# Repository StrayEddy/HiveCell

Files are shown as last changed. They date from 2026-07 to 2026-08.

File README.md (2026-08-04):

# HiveCell



**🌐 Project site & demo video: [strayeddy.github.io/HiveCell](https://strayeddy.github.io/HiveCell/)**

> **Open-source hardware research — uncertified, not a deployable product.**
> HiveCell moves a powered steel piston through a space a person occupies. It is
> **design and simulation only**: no built hardware, no physical validation, no
> safety certification. **Do not build this to put a person inside it.** See
> [`LICENSE`](LICENSE) for the full safety notice and licensing.

Modular public sleeping infrastructure. Each cell is a recessed cavity in a large
wall that provides one clean, safe overnight sleeping space. When unavailable, the
cavity retracts into the wall until the public face is flush, moving the sleeping
surface into a hidden service area for automated cleaning.

Design priorities (in order): vandal resistance, hygiene, reliability, low
maintenance, low energy, low cost, simplicity, easy servicing, long lifetime.
Comfort is intentionally low priority.

## Mechanism

**True syringe (Option B):** a single piston moves inside a fixed tube (barrel).
Retracted, the piston is the floor/back of an open sleeping capsule. Advanced, its
own face becomes the flush public wall — no separate door. The sweep of the piston
performs cleaning and seals the cavity on the hidden service side.

## Safety status

This machine moves a powered steel piston through a space people occupy, and users are
assumed VULNERABLE (asleep, intoxicated, unwell) and unable to self-rescue — so safety
is the first design constraint, not a feature. Full analysis in
[`docs/SAFETY.md`](docs/SAFETY.md) (hazards, FMEA, safety functions); the numbered
requirements, verification matrix, fault trees and — most usefully — the register of
what is *not* yet verified in [`docs/TRACEABILITY.md`](docs/TRACEABILITY.md); decisions
in [`docs/DECISIONS.md`](docs/DECISIONS.md).

Current state — **design + simulation / first-order analysis, no certified hardware yet:**

| Safety function | Status |
|---|---|
| SF1 Occupancy detection (primary) | fail-safe voting logic + self-test; architecture decided — diverse-redundant suite (radar vitals + thermal + CO₂ + load/BCG), target ISO 13849 PL e (ADR-0012) — `[sim]` |
| SF2 Contact-force reaction (safety edge) | independent force-cap trip in the twin + self-test — `[sim]` |
| SF3 Gap-filling wiper seal | CAD geometry + drag budget; low friction now required (ADR-0011) — `[cad]` |
| SF4 Fail-open drive (no occupant release) | decided: back-drivable + passive flush latch + ~1.5 kN return spring (ADR-0009; required per the pin-relief check); fail-open, latch and no-auto-restart now in the twin + machine-checked, external E-stop is a Category 0 stop into the same path (ADR-0023) — `[decision + sim]` |
| SF5 Motion signalling + soft profile | soft velocity profile + signalling (green ready / red moving / orange closed / flashing-red alarm) in the twin + self-test — `[sim]` |

The SF1+SF2 interlock is a shared, headless-testable state machine; its core invariant
— *the sweep never advances while a safety trip is active* — is enforced by a self-test
that gates every push (see Setup), and **formally verified over all reachable states**
by a TLA+ model ([`spec/`](spec/README.md)) in that same gate. The strongest proven
claim is that the piston never drives past a real occupant *even with all four
life-detection channels blind* — the FMEA F1→F2 defence-in-depth chain. The design
principle is PREVENT (never move while occupied) → REACT (stop & reverse on contact) →
fail safe; "push the occupant out" is not a mode the machine can enter.

**Notable decisions** (full rationale in `docs/DECISIONS.md`): the fail-open + return-spring
requirements challenge the original rigid-chain actuator, so the **drive architecture is
under review** (ADR-0010, *proposed*). H4 (fall from the mouth) is a **documented
accepted-risk trade** — a sitting-height sill for object-clearing leaves fall protection
resting on SF1 alone (ADR-0013); recorded transparently, with the safer alternative noted.

**Biggest open risk:** seal drag is the master variable — it couples the seal (SF3), the
SF4 return spring, and the actuator size, yet is currently only estimated (~16–700 N/m).
It must be measured on a real seal sample before the force numbers are frozen (ADR-0011).
A ~$200 bench procedure to do exactly that — the highest-value next experiment, and a
great first contribution — is in [`docs/seal_drag_bench_test.md`](docs/seal_drag_bench_test.md).

Everything above is design/simulation and first-order analysis. Real progress from here
is physical-world validation: bench-measure seal drag, prototype the SF1 radar, and build
the certification dossiers (ISO 13849 PL e for SF1; force/injury data for SF2).

## Software stack

| Tool | Role |
|---|---|
| FreeCAD  | Mechanical design (parametric, source of truth) |
| Godot | Motion simulation & digital twin |
| Blender  | Rendering & presentation (later only) |
| Git | Version control |

## Layout

- `cad/`     — FreeCAD models (parametric)
- `docs/`    — engineering notes, calculations
- `godot/`   — simulation / digital twin project
- `spec/`    — TLA+ formal model of the safety interlock ([what it proves](spec/README.md))
- `blender/` — rendering assets (later)
- `docs/DECISIONS.md` — engineering decision log (read this first)
- `docs/SAFETY.md`   — machine-safety analysis (hazards + safety functions)
- `docs/TRACEABILITY.md` — safety requirements, Hazard→Requirement→Design→Verification matrix, fault trees, gap register
- `docs/ROADMAP.md`  — prioritized roadmap, indexing the [GitHub Issues](https://github.com/StrayEddy/HiveCell/issues)

## Setup

The piston retracts into a space people occupy, so its motion is gated behind a
life-detection interlock (`godot/safety_interlock.gd`, per `docs/SAFETY.md`). A
headless self-test enforces the core invariant — the clearing sweep never
advances while life is detected — and a pre-push hook blocks pushes if it fails.

That invariant is also **machine-proven over every reachable state** by a TLA+ model
([`spec/`](spec/README.md)), which runs in the same gate. It needs a JRE
(`sudo pacman -S jre-openjdk` or equivalent); without one it is skipped locally with a
warning rather than blocking you, and `HIVECELL_SKIP_MODELCHECK=1` skips it
deliberately.

**CI is the authority, not the local hook.** `.github/workflows/safety.yml` runs the
twin self-tests and all three model-check configurations on every push and pull
request, plus the mutation suite that proves those checks can still fail — with the
Godot and TLA+ versions pinned, so a toolchain bump is a visible commit rather than a
silent change in what the gate accepts. Nothing there is skippable.

After cloning, enable the hook once (it lives in `.githooks/`, but `git` must be
pointed at it):

```sh
git config core.hooksPath .githooks
```

Run the self-tests manually anytime (set `GODOT_BIN` if Godot isn't on `PATH`):

```sh
./scripts/run_selftest.sh
```

## License & contributing

HiveCell is open-source, licensed by file type so each part uses the right license
for its medium:

- **Hardware** (`cad/`, `blender/`, `renders/`) — CERN-OHL-S-2.0 (strongly reciprocal)
- **Documentation** (`docs/`, this README) — CC-BY-4.0
- **Software** (`godot/`, `scripts/`, `spec/`) — Apache-2.0

You may use, modify, and redistribute — including commercially — with attribution;
hardware derivatives must stay open under the same terms. Full texts are in
[`LICENSES/`](LICENSES/); the scheme and the **safety notice** are in
[`LICENSE`](LICENSE).

Some cinematic cast motion is derived from [Mixamo](https://www.mixamo.com/)
animations, used under Adobe's royalty-free terms. The source Mixamo FBX are not
committed, but the baked `blender/narrative.blend` (the cinematic's source of
truth) does embed the retargeted motion — re-bakeable via
`blender/retarget_mixamo.py`. That motion is Mixamo's, not CC0.

Contributions are welcome — see
[`CONTRIBUTING.md`](CONTRIBUTING.md); the most valuable one right now is a real
bench measurement of seal drag (ADR-0011).

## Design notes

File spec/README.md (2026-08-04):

# HiveCell — formal model of the safety interlock

Machine-checked proof of the interlock's safety claims over **all** reachable states,
rather than the hand-written scenarios in `godot/tests/test_interlock.gd`.
Roadmap [#1](https://github.com/StrayEddy/HiveCell/issues/1).

```
./scripts/run_modelcheck.sh              # the three green runs   (~70 s)
./scripts/run_modelcheck.sh --deep       # Steps=6, DwellTicks=3  (~2 min 40 s)
./scripts/run_modelcheck.sh --mutants    # prove the checks bite  (~2 min)
```

Needs a JRE (`sudo pacman -S jre-openjdk`) — `tla2tools.jar` is downloaded to
`~/.cache/hivecell/` on first run. Nothing is vendored into the repo.

| Run | Environment | Proves |
|-----|---|---|
| `Safety.cfg` | adversarial — any sensor reading, any trip, any power/E-stop event, people entering and leaving, at every tick | the 7 invariants + 5 action properties below |
| `Liveness.cfg` | benign — nothing ever wrong | the machine actually *works*: the item gets cleared, the pod returns to service |
| `Blackout.cfg` | FMEA **F3** — SF1 wholly blind with a real occupant inside, power fails at any moment and never returns | the SF4 pin relieves |

Current result: **all three pass** (29,892 / 22 / 264 distinct states) and all 9
injected defects are caught.

---

## What is verified

Stated as invariants (hold in every reachable state) and action properties (hold
across every transition — these are the formal analogue of the per-frame assertion
in `test_interlock.gd::_run()`, which state invariants cannot express).

| Name | Claim | Traces to |
|---|---|---|
| `Inv_NoAdvanceWhileOccupied` | a sweep is never underway while any life signal or sensor fault is present | SF1, H1/H6 |
| `Inv_SweepNeedsAllChannelsClear` | a sweep runs only when **every** diverse channel positively reads CLEAR | ADR-0012 "AND toward clear" |
| `Inv_FaultMeansNoSweep` | a faulted/stale channel stops the machine exactly as a life reading would | ADR-0012 "fault = occupied" |
| `Inv_NoSweepWhileContact` | the safety edge alone also forbids a sweep, independently of SF1 | SF2 |
| `Inv_EStopHalts` | E-stop or power loss ⇒ the machine is in its fail-open state, not driving | ADR-0009/0023 |
| `Inv_BlockedIsStill` | refusing to move means actually standing still, at the open end | SF1 |
| **`Inv_NoCrush`** | **the piston never drives past a real occupant — even with all four SF1 channels blind** | **FMEA F1→F2** |
| `Inv_NoTripHeldAtFlush` | the pod never sits closed-and-flush with either trip asserted | SF2, H8, ADR-0022 |
| `P_NoAdvanceUnderLife` | no inward motion on any tick whose life reading says occupied | SF1 |
| `P_NoAdvanceUnderContact` | no inward motion on any tick with the edge tripped | SF2 |
| `P_NoAdvanceUnpowered` | an unpowered drive cannot close the pod | SF4 |
| `P_NoTeleport` | the piston moves one step per tick; it never resets position instead of reversing through it | — |
| `P_NoAutoRestart` | restoring power or releasing the E-stop never resumes the sweep | ADR-0009/0023 |
| `P_BagEventuallyCleared` | benign case: the item left behind really does get cleared | liveness |
| `P_ReturnsToService` | the cycle returns to service rather than parking closed | liveness |
| `P_PinRelieves` | with power gone, the piston never rests pinned mid-stroke | SF4, FMEA F3 |

Every claim above is verified against the shipped FSM.

`Inv_NoCrush` is the one that earns the "defence in depth" phrase in `SAFETY.md`.
The other SF1 claims are all *sensor-relative* — they say the machine obeys its
sensors, which is not the same as saying nobody gets hurt. `Inv_NoCrush` is stated
over a **ground-truth occupant** the sensors may miss entirely, so it holds even in
the FMEA F1 case where all four channels read false-empty. Scenario S5 in
`test_interlock.gd` checks this at one hand-picked position; here it holds for every
occupant position in every reachable state.

---

## Model ↔ code correspondence

The spec is a hand-written model, not generated from the GDScript, so this table is
the thing to re-check when either side changes.

| TLA+ | GDScript |
|---|---|
| `FsmStates` | `enum State` — same seven, `UNPOWERED` included |
| `Available`, `LifeCheck`, `Clearing`, `ClearedHold`, `Redeploy`, `BlockedOccupied` | the six `match state:` branches of `step()` |
| `FailOpen` | `_fail_open()` — SF4 relief + flush latch |
| `Recover` | `_recover()` — back out, never resume |
| `DriveOf(es, pw)` | `drive_powered()` |
| `powered`, `estop` | `powered`, `estop` |
| `Verdict(v)` | `life_present()` `:48–53` → `OccupancyFusion.occupied()` `occupancy_fusion.gd:102–106` |
| `LifeOf(v)` | *specification only* — see "Why `LifeOf` and `Verdict` are separate" |
| `Edge(ct)` | `contact_over_limit` (SF2) |
| `vote ∈ [Channels → Votes]` | the four `Channel`s and their `vote()` `occupancy_fusion.gd:47–50` |
| `FaultOf` | `Channel.faulted()` — unhealthy ∨ implausible ∨ stale `:44–45` |
| `dwell` / `DwellTicks` | `clear_dwell` / `life_check_seconds` |
| `hold` / `HoldTicks` | `t` / `hold_seconds` |
| `progress ∈ 0..Steps` | `progress ∈ [0.0, 1.0]` |
| `bag` | `bag_present` |
| `Tick` atomicity | `step(delta)` reads the sensor fields as they stand when it runs |

### Why `LifeOf` and `Verdict` are separate

They are equal in the unmutated spec, and deliberately not collapsed:

- `LifeOf` is the **specification** of occupancy — only the invariants use it.
- `Verdict` is the **mechanism** the state machine consults — only the FSM uses it.

Without the split, a defect injected into the voter would weaken the very invariant
meant to catch it, and the mutation suite would report a false pass. `Edge(ct)` plays
the same role for SF2. Don't merge them.

### Abstractions (where the model is *not* the code)

Each of these is a place the proof is narrower than reality. They are the honest
limits of what the green runs establish.

1. **Discrete travel.** `progress` is `0..Steps` (4 by default), not a real in
   `[0,1]`. Preserved: monotone advance only in `CLEARING`, monotone retreat in
   `REDEPLOY`, and one step per tick. Abstracted away: the SF5 velocity shaping in
   `soft_profile.gd`. The model proves *whether* the piston may move and in which
   direction; it says nothing about *how fast*. `--deep` re-runs at `Steps = 6`.
2. **Discrete time.** Timers are tick counts, and `hold` **saturates** at
   `HoldTicks` (the code only ever compares `t >= hold_seconds`, so values past the
   threshold are indistinguishable). Sound for these claims, and it keeps the state
   space finite.
3. **`reverse_from` is dropped.** In the code it only sets the reverse stroke's
   soft-profile span — an SF5 velocity detail. It cannot affect *whether* progress
   decreases, which is all the model claims.
   Likewise the unpowered return *rate* (`return_seconds`) is a placeholder on both
   sides: the real rate is spring force minus seal drag, and seal drag is the
   project's master unknown (ADR-0011, issue #9). Only the **direction** of the
   relief and the fact that it **completes** are claimed.
4. **One occupant, stationary.** They may enter or reach in at any time, but only
   ahead of the piston face (FMEA F5 geometry), and they don't move once inside.
5. **The safety edge is perfect.** `SafetyEdgeOK` *forces* `contact` true whenever
   the face is against the occupant. A failed-blind SF2 is therefore **out of
   scope** — the model proves SF2 backstops SF1, not that SF2 itself cannot fail.
   Diverse-redundant SF2 is not modelled and remains a hardware/PL question.
6. **Sensor channels are free.** Any channel may false-positive or false-negative at
   any tick, independently. This is deliberately *weaker* than reality (real
   channels correlate) and so is the safe direction — except for common-cause
   failure, which ADR-0012 addresses by physics diversity, not by logic, and which
   this model cannot speak to.
7. **`Steps = 4` is not a proof for all `Steps`.** TLC checks a finite instance.
   `--deep` raises it; neither is induction over the parameter.

---

## SF4: how the model drove the implementation

Worth recording, because it is the reverse of the usual order.

Two of issue #1's four named invariants originally had **nothing to check against**:
`safety_interlock.gd` had no E-stop input and no notion of power at all, even though
`SAFETY.md` retained an external/operator E-stop and ADR-0009 makes the fail-open
drive the entire answer to FMEA F3. Rather than drop those claims, the spec modelled
them — an `UNPOWERED` state plus `FailOpen` / `Recover` — and they sat verified
against *intent* while the code had no counterpart.

Writing that model forced a question nobody had answered: **what does pressing the
E-stop actually do?** ADR-0009 named the E-stop but never specified its behaviour. The
model had to commit to something, and the only choice consistent with SF4 was Category
0 — cut drive power, inherit the fail-open path — because a freeze-in-place E-stop
recreates FMEA F3 exactly, the failure that forced SF4 in the first place. That is now
**ADR-0023**, and the twin implements it.

So the sequence ran spec → decision → code, and the properties that were the model's
guesses are now the implementation's tests. Both sides are checked by the same names:

| Claim | Model | Twin |
|---|---|---|
| E-stop / power loss cuts the drive | `Inv_EStopHalts` | S9 |
| no inward motion unpowered | `P_NoAdvanceUnpowered` | `_run()` per-frame check |
| the pin relieves; no held mid-stroke | `P_PinRelieves` | S7 |
| the flush latch holds without power | `FailOpen` at `Flush` | S8 |
| release never resumes the sweep | `P_NoAutoRestart` | S9 |

---

## Findings

### F-1 — `CLEARED_HOLD` ignored both safety trips — **fixed, ADR-0022**

The first thing this model found, and the concrete argument for doing any of it: a
real defect in shipped logic that had survived both review and the scenario self-test.

`safety_interlock.gd`'s `CLEARED_HOLD` branch tested only `t >= hold_seconds` — it
never re-read SF1 or SF2. With the piston flush at the mouth, a safety-edge trip was
therefore not acted on until the dwell expired, **2.0 s** at the twin's default.

TLC reached it two ways: a spurious edge trip at flush (the shortest trace), and the
one that matters — someone reaches into the mouth (**H5**) at the exact position the
piston is completing to, and is held against the flush face for the rest of the dwell.
That is **H8**, the mouth-lip pinch, precisely where SF2 is supposed to act.

Bounded, not a crush: `Inv_NoCrush` held throughout — the piston never drove *past*
them, and contact stays at the SF2 cap (100 N, sourced from injury/biomechanical data
— see `docs/force_limit_injury_data.md`, ADR-0024).
The defect was in the *latency* of the response, not its existence. But SF2's
specified response is "immediate stop and reverse", and up to a full dwell is not
immediate.

**Why the scenario tests missed it.** Every hand-written scenario trips SF1 or SF2
*mid-sweep*, because that is the moment an author thinks of as dangerous. None of them
trips it while the pod is already closed — the state that intuitively reads as "safe,
nothing is moving". Exhaustive exploration has no such intuition.

Fixed by giving `CLEARED_HOLD` the same two trips `CLEARING` has. Now guarded three
ways: `Inv_NoTripHeldAtFlush` in `Safety.cfg`, scenario S6 in `test_interlock.gd`, and
the `hold-ignores-trips` mutant, which re-injects the exact pre-fix code so the guard
cannot rot silently.

No open findings.

---

## Why the mutation suite exists

A spec that passes proves nothing unless it *can* fail — a model with a typo in a
guard, or an invariant that is true by construction, passes just as greenly as a
correct one. `--mutants` injects eight real defects, most of them designs the ADRs
explicitly rejected, and **fails if TLC does not catch each one**.

| Mutant | Defect | Caught by |
|---|---|---|
| `sf1-ignored` | the FSM never consults life detection | `Inv_NoAdvanceWhileOccupied` |
| `fault-reads-clear` | a faulted channel stops failing safe | `Inv_NoAdvanceWhileOccupied` |
| `majority-vote` | 2-of-4 instead of "AND toward clear" | `Inv_NoAdvanceWhileOccupied` |
| `sf2-ignored` | the safety edge is never consulted | `Inv_NoSweepWhileContact`, and `Inv_NoCrush` independently |
| `self-locking-drive` | the drive holds position without power (FMEA F3) | `P_PinRelieves` |
| `auto-restart` | releasing the E-stop resumes the sweep | `P_NoAutoRestart` |
| `snap-home` | the piston teleports home instead of reversing | `P_NoTeleport` |
| `hold-ignores-trips` | `CLEARED_HOLD` stops re-reading the trips — *the pre-ADR-0022 defect verbatim* | `Inv_NoTripHeldAtFlush` |
| `frozen-sweep` | the machine never moves — safe but useless | `P_BagEventuallyCleared` |

Writing this suite is what caught the one weak check in the first draft:
`Inv_FaultMeansOccupied` was stated as `FaultOf(vote) ⇒ LifePresent`, which is true
by construction and checks nothing about the machine. It is now
`Inv_FaultMeansNoSweep`, stated over the FSM's state, and `fault-reads-clear` bites.

Mutations are `sed` expressions over the module text, so they are brittle by
construction — a mutation that no longer applies is reported as an `ERROR`, not
silently skipped.

---

## What this does *not* establish

- **No PL rating.** This is logic, not certified hardware. ISO 13849 PL e for SF1
  needs rated parts and a rated controller (ADR-0012) — untouched by any of this.
- **The model is hand-written.** It can drift from the GDScript. The correspondence
  table above is the mitigation; re-check it when either side changes.
- **Timing is abstracted.** Dropouts, races, stall detection and power-loss position
  live in the continuous layer this model deliberately collapses — that is roadmap
  [#3](https://github.com/StrayEddy/HiveCell/issues/3), and it stays open.
- **SF2 cannot fail here** (abstraction 5), so "SF2 backstops SF1" is proven while
  "SF2 is itself trustworthy" is not.

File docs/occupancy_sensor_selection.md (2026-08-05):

# SF1 occupancy sensing — candidate parts & prices (issue #4, ADR-0012/ADR-0025)

**Goal:** put real part numbers and prices against the diverse channels ADR-0012
decided on, as flagged in [`SAFETY.md`](SAFETY.md)'s open items ("choose sensor part
numbers") and tracked as [#4](https://github.com/StrayEddy/HiveCell/issues/4). Also
covers the SF2 current-sense hardware, since it's the same "what do we actually buy"
question for issue #8's hardware half.

> **Superseded by ADR-0025.** Placement and suite composition were resolved after this
> survey was first written: **channel C (CO2) is dropped**, **channel D (load cells) is
> provisional** pending a piston-vibration bench test, and **placement is
> crown-mounted (fixed barrel ceiling) for A/B/E, floor-mounted for D, nothing on the
> piston**. Sections below are kept for the part/price research and marked accordingly
> rather than deleted.

> **This is a parts survey, not a certification decision.** Every module below is a
> commodity/prototyping-grade breakout — none of it is safety-rated out of the box.
> ADR-0012 calls for **PL e, Category 3-4** on the fused occupancy function, which
> means: a rated safety controller doing the voting (not the twin's ordinary MCU
> path), and a documented MTTFd/DC/CCF case per ISO 13849-1 for whatever channel
> hardware is finally chosen. The parts here are what you'd buy to **prototype and
> bench-validate each channel's physics** (does 60 GHz radar actually see a breathing
> rate through a blanket at HiveCell's range? does an 8x8 thermal array have enough
> resolution?) — that's the immediate need per #4 and ADR-0012's own accepted-cost
> list ("validate radar vital-sign range/reliability... on real hardware"). Whichever
> part wins the bench-off still has to clear a PL e dossier before it ships.

---

## 1. Channel A — mmWave/UWB vital-sign radar (primary) — crown-mounted

| Part | Vendor | Price (USD) | Grade | Notes |
|---|---|---:|---|---|
| **MR60BHA2** (XIAO 60 GHz mmWave breathing/heartbeat kit) | Seeed Studio | **$26.90** | Prototype | Onboard ESP32C6, outputs presence + breath rate + heart rate over UART already — fastest path to a bench demo. Predecessor MR60BHA1 is discontinued; use MR60BHA2. |
| **XM125** (Acconeer A121 Entry+ radar module) | Acconeer/Digi-Key | **$21.14** | Prototype | Pulsed coherent radar (not FMCW); ships with a presence detector, but vital-sign extraction is DIY (Acconeer's Exploration Tool has the primitives, not a turnkey heart-rate output). |
| **XE125** (Acconeer A121 eval board) | Acconeer/Digi-Key | **$121.09** | Prototype/dev | Full eval platform for the A121 IC above — more I/O and debug access than the bare module. |
| **IWR6843AOPEVM** (60 GHz AoP eval module) | TI | **$195.56** | Industrial dev | Raw ADC/point-cloud access, antenna-on-package. TI publishes a vital-signs reference design (people-counting + breathing/heart-rate) built on this family — the credible path if the Seeed kit's fixed firmware turns out too limited to validate through-bedding performance. |
| BGT60TR13C (bare IC) | Infineon/Digi-Key | **$19.72** | Component | For a from-scratch board once a reference design is chosen; not a plug-in module. |

**Recommendation for the bench pass:** start with the **MR60BHA2 ($27)** — cheapest,
fastest to a working demo, and its firmware already reports breath/heart rate, which is
the exact ADR-0012 open question ("validate radar vital-sign range/reliability through
bedding"). Keep the **IWR6843AOPEVM** in reserve if the fixed-firmware kit can't be
tuned/validated for HiveCell's geometry.

## 2. Channel B — Thermal IR array — crown-mounted, kept (ADR-0025)

No longer purely "supportive" now that C is dropped — see ADR-0025 point 4. It carries
more of the fused vote than ADR-0012 originally assumed.

| Part | Vendor | Price (USD) | Grade | Notes |
|---|---|---:|---|---|
| **AMG8833** (Panasonic Grid-EYE, 8×8) | Mouser | **~$17–40** (single-unit breakout ≈$35–40; ~$17 at MOQ 200) | Prototype | Coarse 8×8 grid — enough for "a warm body-shaped blob is/isn't in the bore." |
| **MLX90640** (Melexis, 32×24) | Mouser | **~$35–70** | Prototype | Higher resolution than AMG8833; only worth the premium if 8×8 proves too coarse to reject e.g. a warm pipe or heater vent as a false positive. |

**Recommendation:** AMG8833 first — cheaper, and the resolution bar is lower than 32×24.

## 3. Channel C — NDIR CO2 — **dropped, see ADR-0025**

~~Independent physics, penetration-independent (works under a blanket)~~ — dropped from
the suite. It was the one channel that categorically cannot take a solid flush window
(gas has to diffuse through something porous), forcing a more exposed, higher-
maintenance baffled vent than any other channel needs. Accepted cost: it was the only
channel that stayed elevated through a breath-hold/apnea event independent of RF
micro-motion; thermal partially, not fully, covers that gap (body heat outlasts a
breath-hold; CO2's chemical persistence doesn't have an exact substitute). Part research
kept below for reference only — not part of the current BOM.

| Part | Vendor | Price (USD) | Grade | Notes |
|---|---|---:|---|---|
| **SCD41** (Sensirion, photoacoustic NDIR, bare sensor) | Digi-Key | **$20.54** | Component | 10×10×6.5 mm, smallest footprint; needs your own board/I2C wiring. |
| **Adafruit SCD-41 breakout** (STEMMA QT) | Adafruit | **$49.95** | Prototype | Same sensor, ready-to-wire breakout. |
| **SCD30** (Sensirion, dual-channel NDIR) | Mouser/Digi-Key | **~$20–40** | Component/prototype | Older, larger, dual-channel-for-stability design. |

## 4. Channel D — Floor load cells + ballistocardiography — floor-mounted, provisional (ADR-0025)

**Provisional, not confirmed.** Stays in the suite only if a bench test (not yet run)
shows piston-drive vibration, coupled through the shared fixed-floor structure, doesn't
swamp the BCG micro-motion signal — or that drive-telemetry reference-subtraction
recovers it. The mass-presence half of this channel (unaffected by vibration, since it's
a static reading, not a micro-motion one) is not in question; the BCG half is. If the
bench test fails, this whole section drops and the confirmed suite is radar + thermal
only.

| Part | Vendor | Price (USD) | Grade | Notes |
|---|---|---:|---|---|
| **50 kg half-bridge load cell + HX711 ADC kit** (4-pack + amplifier) | Amazon/eBay | **~$16–20** for the whole kit | Prototype/hobby | 24-bit HX711 ADC is the standard hobby path to BCG-scale resolution (micro weight-shifts from pulse/breathing) — this is what most published bed/floor-BCG research setups (e.g. the PMC longitudinal-BCG study surveyed here) actually build on. |
| **Single-point load cell, 100 kg or 200 kg capacity** | ATO.com | **$96.56** each | Industrial | For the "static mass = something present" half — 100 kg is plenty of headroom per corner for an adult occupant's weight split across 4 cells; the HX711 kit's 50 kg hobby cells are undersized once you're load-bearing rather than just sensing micro-motion. |

**Recommendation:** this channel actually needs **two different grades doing two
different jobs** — the coarse "is there load-bearing mass at all" reading wants the
industrial 100 kg single-point cells (4 per cell, corners, **~$390** for the set) sized
for real body weight; the BCG micro-motion signal on top of that can run off the same
cells through a 24-bit HX711 front end (~$5–10 per channel) rather than needing separate
hardware — no need to buy the 50 kg hobby load cells too.

## 5. Channel E — mouth-plane presence during motion — mouth-frame-mounted, not crown — **required, not optional**

**Correction:** earlier drafts of this doc (and this survey's own framing further down)
called E optional, following ADR-0012's original text. That's stale — **ADR-0016
already promoted channel E to required**, months before this survey (`DECISIONS.md`
line 701: *"the mouth-plane presence sensor (ADR-0012 optional channel E) is promoted
to required"*, driven by the cleaning-cycle reach-in hazard, not the H4 siting
follow-up this doc previously pointed to). That changes the sourcing conclusion below:
this needs to *be* a certified safety function from the start, not a bench-validation
placeholder with certification deferred.

| Part | Vendor | Price (USD) | Grade | Notes |
|---|---|---:|---|---|
| **VL53L5CX breakout** (8×8-zone ToF) | SparkFun/Pololu | **~$32.50** | Prototype | Useful now for bench characterization of the reach-in geometry/timing, but it is a consumer ToF chip — not safety-rated, no certified stop path. Not a substitute for the certified part below; bench-only. |
| **Omron F3SG-4RA / F3SJ safety light curtain**, PL e / Cat 4 / SIL3 | Omron/Newark | **from ~€529 (~$570+)**, scales with protected height | Safety-certified | This is the part that actually belongs in the BOM, since E is required, not optional — a certified light curtain, not a hobby ToF board doing the same job in software. |

**Recommendation:** VL53L5CX now for bench geometry/timing studies only; the certified
light curtain (~$570+) is the real line item and belongs in the BOM now, not deferred —
E's required status was already decided before this survey was written.

## 6. SF2-adjacent — force/current sensing on the real drive (issue #8 hardware half)

Not an ADR-0012 channel, but the same "what part number" question applies to the other
open hardware item (#8: can the real drive hold the 100 N cap under a jam). Force
limiting on a chain/actuator drive is normally done by motor current sensing, not a
separate mechanical force sensor:

| Part | Vendor | Price (USD) | Grade | Notes |
|---|---|---:|---|---|
| **ACS712** (Hall-effect current sensor, ±30 A) | various/eBay | **~$1.50–8** per breakout | Prototype | Cheapest way to bench-correlate motor current to output force on a test rig; used in exactly this role in hobby linear-actuator projects. |
| **ACS37800** (Allegro, isolated AC/DC power-monitor IC) | Pololu/Mouser/Digi-Key | price not confirmed — check distributor directly | Component/industrial | Reinforced isolation, ±30 A bidirectional, I2C/SPI output — the credible upgrade from ACS712 if the final drive electronics need a certifiable current-sense path rather than a hobby breakout. |

## 7. Rough bench-validation BOM (one cell, prototype-grade, per-unit qty 1)

| Channel | Part | Price |
|---|---|---:|
| A — radar | MR60BHA2 (bench) | $26.90 |
| B — thermal | AMG8833 (bench) | ~$38 |
| ~~C — CO2~~ | *dropped, ADR-0025* | — |
| D — load/BCG (provisional) | 4× ATO 100 kg single-point cell + HX711 front end | ~$396 + ~$10 |
| E — reach-in (**required**, ADR-0016) | VL53L5CX (bench-only) + Omron F3SG-4RA (the real part) | $32.50 + $570+ |
| SF2 current sense | ACS712 breakout | ~$5 |
| **Total, bench-validation channels only (A/B/D/SF2)** | | **≈ $476/cell** |
| **+ E's certified light curtain (required, not deferrable)** | | **≈ $1,050+/cell** |
| **If D fails its bench test** | | **≈ $650+/cell** (A + B + E + SF2) |

This is a single bench-validation set for A/B/D, not a BOM for a certified unit for
those three — final parts there will likely change once the PL e dossier and real
mounting/EMC constraints (radar-in-metal-bore, per ADR-0012's accepted costs) are
worked out. E is different: it's already a required safety function, so its certified
part cost is real and not a placeholder.

## 8. What this doesn't answer

- No pricing here reflects volume/production cost — these are single-unit
  prototyping prices only.
- None of these parts carry a safety certification; the PL e dossier (category,
  MTTFd, DC, CCF per ISO 13849-1) still has to be built once parts are chosen, per
  ADR-0012's follow-ups and `SAFETY.md`'s open items.
- Radar-through-metal-bore EMC and mounting/field-of-view (no dead zones) are
  unverified for all radar candidates above — bench characterization, not a catalog
  lookup, will decide this.
- Channel E is required (ADR-0016), not optional — see the correction in §5. It also
  interacts with H4/ADR-0013's sitting-height siting, but that's a second reason to
  need it, not the original one.

## Sources

- [Seeed Studio — MR60BHA2](https://www.seeedstudio.com/MR60BHA2-60GHz-mmWave-Sensor-Breathing-and-Heartbeat-Module-p-5945.html)
- [Acconeer A121 / XM125 / XE125](https://www.waveshare.com/a121-range-sensor.htm)
- [TI IWR6843AOPEVM](https://www.ti.com/tool/IWR6843AOPEVM)
- [Infineon BGT60TR13C — Digi-Key](https://www.digikey.com/en/products/detail/infineon-technologies/BGT60TR13CE6327XUMA1/13282953)
- [Panasonic AMG8833 — Mouser](https://www.mouser.com/ProductDetail/Panasonic/AMG8833)
- [Melexis MLX90640 — Mouser](https://www.mouser.com/new/melexis/melexis-mlx90640-fir-sensor)
- [Sensirion SCD41 — Digi-Key](https://www.digikey.com/en/products/detail/sensirion-ag/SCD41-D-R2/13684004)
- [Adafruit SCD-41](https://www.adafruit.com/product/5190)
- [Sensirion SCD30](https://sensirion.com/products/catalog/SCD30)
- [ATO.com — single point load cell](https://www.ato.com/single-point-load-cell-300g-to-500kg)
- [VL53L5CX — SparkFun](https://www.sparkfun.com/sparkfun-qwiic-tof-imager-vl53l5cx.html)
- [Omron F3SG-4RA safety light curtain — Newark](https://www.newark.com/omron-industrial-automation/f3sg4ra120014/safety-light-curtain-cat4-1-2m/dp/74Y6328)
- [Allegro ACS37800 — Pololu](https://www.pololu.com/category/343/acs37800-isolated-power-monitor-carriers)
- [ACS712 current-sense-for-actuator-limits example](https://www.instructables.com/Using-an-Using-an-ACS712-and-Arduino-to-detect-act/)

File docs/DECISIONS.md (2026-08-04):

# Engineering Decision Log

Append-only record of significant engineering decisions (an ADR — Architecture
Decision Record — log). Each entry: what we decided, why, and what it rules out.
Newest at the bottom.

---

## ADR-0001 — Motion principle: true syringe (Option B)
**Date:** 2026-07-21
**Status:** Accepted

**Decision.** A single cell moves as a piston inside a fixed tube ("barrel").
- Retracted: the piston sits deep; the open tube ahead of it is the sleeping cavity;
  the piston face is the surface the occupant rests against.
- Advanced: the piston travels to the wall plane; its face becomes the flush public
  wall. No separate door or plug. The cavity now lies behind the piston, on the
  hidden service side, sealed and ready for cleaning.

**Why.** Fewest moving parts (one piston, one actuator) → best score on reliability,
cost, simplicity. Cylindrical bore has no corners → best hygiene and vandal
resistance. Cleaning is intrinsic to the stroke (piston sweeps the bore). One part
serves as both resting surface and flush closure.

**Rejected alternatives.**
- A — Linear shuttle/drawer + separate flush plug: more parts, more seals, plug is
  its own mechanism.
- C — Rotary/carousel swap of two pods: zero downtime but most mechanism and failure
  modes; conflicts with simplicity/reliability priorities.

**Accepted costs / constraints.** Sleeping space is a capsule; stroke is roughly one
body length (~2.1 m target, TBD in M1); installation depth ~4 m front-to-back
(cavity + service chamber). These must be validated against real building envelopes.

---

## ADR-0002 — Authoring workflow: code-first FreeCAD scripting
**Date:** 2026-07-21
**Status:** Accepted

**Decision.** The model is authored as git-tracked Python (`scripts/build_model.py`)
run headless via `freecadcmd` (FreeCAD Flatpak). The Python is the source of truth;
`cad/HiveCell.FCStd` is a generated build artifact. The FreeCAD GUI is used only to
view/measure, never to hand-edit geometry (edits would be overwritten on regenerate).

**Why.** User is an experienced software engineer who wanted to move fast and keep
the design in code/version control. FreeCAD's Python API gives full parametric
control (sketches, constraints, pads, spreadsheet) while retaining manufacturing-
grade BREP output, STEP export, the free GUI viewer, and an early motion-preview
path. Beats manual clicking (speed) and OpenSCAD (mesh/CSG, weak STEP).

**Rejected alternatives.**
- Manual GUI modeling: too slow; not diffable.
- CadQuery/build123d: elegant pure-Python BREP, but blocked on this machine by
  Python 3.14 (no OpenCASCADE wheels yet); would need a separate 3.12 env + a viewer
  add-on, and has no motion preview. Revisit later if desired.
- OpenSCAD: not installed; CSG/mesh, poor STEP export -- unfit for "manufacturable".

**Regenerate command.**
`flatpak run --command=freecadcmd org.freecad.FreeCAD scripts/build_model.py`

---

## ADR-0003 — Cross-section: rounded rectangle (capsule), not a cylinder
**Date:** 2026-07-21
**Status:** Accepted (amends the "cylindrical bore" note in ADR-0001)

**Decision.** The living space is a rounded-rectangular capsule (Japanese
capsule-hotel style): a box extruded along +X whose four long edges are rounded
(`cornerRadius`). Ends are flat. The flat back face is the piston that pushes
in/out and seals flush with the exterior wall; the front face is the entry opening.

**Why.** User requirement: a capsule pod is more usable and recognizable than a
round tube, while a flat floor (`floorWidth = cavityWidth - 2*cornerRadius`) gives a
real lying surface. Rounded corners preserve the hygiene/vandal-resistance rationale
(no sharp internal corners); a flat back is required so the piston can seal flush.

**Parameter change.** Replaced `boreDiameter` with `cavityWidth` (1000), reused
`interiorHeight` (950) as capsule height, added `cornerRadius` (125). `floorWidth`
is now derived and checked to exceed `shoulderP95`.

---

## ADR-0004 — Capsule shell = fixed barrel, an open-ended sleeve
**Date:** 2026-07-21
**Status:** Accepted

**Decision.** The `CapsuleShell` is the fixed barrel: a rounded-rectangular sleeve
of uniform `wallThickness`, shelled OUTWARD from the keep-out envelope (inner surface
= envelope; outer corner R = inner R + t). It is open at BOTH ends -- front (X=0) =
public opening / piston seal plane; back (deep) = service side. The flat back wall the
occupant perceives is the PISTON (a separate part, next milestone), not the shell.

**Why.** Shelling outward keeps the human envelope sacred. An open-ended sleeve is the
true syringe barrel and keeps each part independently manufacturable. Uniform wall
(concentric corners) eases fabrication and stress. Built as a boolean cut of two
rounded boxes and baked as a Part::Feature (Python is the source of truth, ADR-0002).

**Placeholders.** `wallThickness` 6 mm is structural TBD (vandal/load analysis).
`barrelLength` = `cavityLength` for now; must extend deeper to house the retracted
piston + actuator once the piston is sized (M4).

---

## ADR-0005 — Piston: the single moving part
**Date:** 2026-07-21
**Status:** Accepted

**Decision.** The `Piston` is a rounded-rectangular plug riding in the bore with a
`runningClearance` (3 mm/side), so cross-section = bore minus 2*clearance and
pistonR = cornerRadius - clearance. `pistonLength` = 300 mm. Modeled at the DEPLOYED
position: flat front face at X=cavityLength (the occupant's back wall), body extending
to X=cavityLength+pistonLength. Its front face becomes the flush exterior wall when
closed. Consequently `barrelLength = cavityLength + pistonLength`.

**Why.** A running fit prevents binding; wiper seals (later) bridge the 3 mm gap and
squeegee the bore, separating public/service sides. Piston depth resists tilt/jam.
Modeling in the deployed pose means the whole mechanism's motion is ONE part
translating -X by `stroke` -- ideal for the Godot digital twin.

**Placeholders.** Solid plug now; lightweighting (ribs / shelled face) and seal
grooves are later milestones. `pistonLength` and `runningClearance` are tunable.

---

## ADR-0006 — CAD -> Godot export conventions
**Date:** 2026-07-21
**Status:** Accepted

**Decision.** `scripts/export_godot.py` writes one OBJ per part to `godot/models/`
plus `hivecell.json` (stroke, timings). Every mesh is baked to Godot space at export:
scale x0.001 (mm->m) and rotate -90 deg about X (FreeCAD Z-up -> Godot Y-up), i.e.
(x,y,z) -> (x, z, -y). The +X motion axis is preserved, so retraction is a single
-X translation of the Piston node. Godot digital twin lives in `godot/` (Godot 4).

**Why.** Baking units + axis at export means Godot needs no per-import fiddling and
parts keep correct relative positions. One mesh per part keeps the piston an
independent, animatable node. The JSON manifest keeps the twin in sync with the
parametric model instead of hardcoding dimensions.

**Rule.** Any new part added to the model must be added to `PARTS` in export_godot.py
and (if it moves) wired in the Godot scene.

---

## ADR-0007 — Drive: central electric linear actuator; bore-as-guide (no external rails)
**Date:** 2026-07-21
**Status:** Accepted

**Decision.** A single central electric linear actuator (self-locking lead/ball
screw preferred) behind the piston in the service area drives the stroke. The rod
is RIGID and fixed-length: it is attached to the piston, TRANSLATES with it, and
telescopes into the fixed housing (it never changes length). Guidance is NOT
external rails but the "syringe" scheme: (1) the bore guides the piston laterally at
the front via wear rings; (2) the non-circular section prevents rotation for free;
(3) the actuator supports the rear. Representative geometry: rod 70 mm dia; housing
160 mm dia x (stroke + 150) = 2350 mm.

**Depth consequence (important).** A rigid push-rod over the full 2.2 m stroke needs
~one stroke of depth behind it to retract into, so total install depth behind the
wall = **4.91 m**. RESOLVED in ADR-0008: a rigid-chain actuator was chosen instead,
cutting depth to 2.86 m.

**Why external rails were rejected.** Linear rails run alongside the travel, outside
the part; connecting them to a piston inside a sealed bore needs a longitudinal SLOT
through the barrel wall -> breaks the seal and hygiene barrier. The syringe topology
forbids it, and provides guidance intrinsically instead.

**First-order sizing (scripts/actuator_sizing.py; assumptions flagged there).**
- piston mass SOLID = 2579 kg -> the model demands lightweighting; ~160 kg as a 6 mm
  shell. Real piston = face plate + ribs (future milestone).
- seal drag dominates: 595 N of 611 N resistive (seals are the thing to engineer).
- design force ~1221 N (x2 SF) -> a modest electric cylinder.
- speed 3.67 mm/s; power ~4.5 W elec; energy 0.75 Wh per stroke (negligible).

**Type choice.** Electric screw over hydraulic/pneumatic: no fluid/compressor
(hygiene, maintenance), self-locking holds the flush piston with zero power and
resists a vandal push (priorities #1/#3/#5).

**Placeholders.** Actuator geometry is representative (space claim), not a selected
unit. Seal drag is the biggest unknown -> validate by test.

---

## ADR-0008 — Actuator architecture: rigid-chain ("zip-chain"), not telescoping rod
**Date:** 2026-07-21
**Status:** Accepted — but **challenged by ADR-0010 (proposed)**: SF4 (ADR-0009) wants
a back-drivable drive, which negates rigid-chain's self-locking advantage. See ADR-0010.

**Decision.** Drive the piston with a rigid-chain actuator: a chain whose links lock
straight to PUSH and bend to coil into a compact flat magazine (no long retract tube).
Parts: `ChainMagazine` (fixed, 300 deep x 650 sq) + `ChainColumn` (the exposed rigid
column; variable length -- physically correct, chain feeds from the coil).

**Why.** Cuts install depth from 4.91 m (rigid rod) to **2.86 m** -- a wall of cells
can't afford ~5 m of back-of-house per unit. Rigid chain is proven (stage lifts /
Serapid). Trade: a more complex drive than a plain screw (mild hit to
simplicity/reliability), accepted for the space saving.

**Twin note.** `ChainColumn` is procedural with a variable length -- correct here
because chain length is conserved (column + coil = const), unlike a solid rod. The
earlier stretching *rod* was wrong; a stretching *chain column* is right.

**Placeholders.** Chain cross-section, magazine size are representative; real sizing
(link geometry, coil radius, drive sprocket, motor) TBD. Force numbers from ADR-0007
hold (~1.2 kN design; seal drag dominates). Validated headless on Godot 4.7.1.

---

## ADR-0009 — SF4 as a fail-open drive + passive flush latch (no occupant release)
**Date:** 2026-07-21
**Status:** Accepted

**Context.** H7 (trapped under self-locking hold) and the SAFETY.md FMEA row F3: if
SF1 mis-detects an occupant and power is lost mid-contact, a self-locking drive holds
a sustained pin with no powered reverse — Severity 4, and nothing can act once power
is gone. Separately, a firm requirement: once fully closed (flush), the pod must STAY
closed without power (security / vandal resistance + zero standby energy).

**Decision.** SF4 is a property of the drivetrain, not an occupant-operated device.
1. **No interior manual release or E-stop.** The geometry already removes the
   sealed-in trap: the occupant is always mouth-side of the piston, so a stopped sweep
   leaves an OPEN pod they can exit (FMEA F4/F5). An accessible release is only a
   vandalism/abuse surface (F7).
2. **Fail-open in the occupant zone.** Through the closing stroke where an occupant
   could be, loss of power must NOT sustain a holding force — the output is
   back-drivable / releases, so a pin relieves passively (F3).
3. **Passive flush latch for "stay closed without power."** A spring / over-center
   latch holds the piston at the fully-closed (flush) end with zero power, engaging
   ONLY in the final travel where the cavity is closed to flush and no occupant can be
   present. A powered solenoid releases it at cycle start to re-open. Deployed (in-use)
   rest is held by a mechanical hard stop.

   => Fail behavior is **position-dependent**: back-drivable in the occupant zone,
   latched only at flush. That is what reconciles "release to free a pin" with "stay
   closed without power" — they apply in different, non-overlapping places.

**Why.** Turns SF4 into a drivetrain property with nothing to touch or break. The
flush latch also *improves* vandal resistance (a closed pod can't be pushed open) and
needs no standby power. No occupant can be pinned where the latch holds (flush), so
holding-without-power there is safe.

**Rejected alternatives.**
- Occupant-operated manual release + interior E-stop: vandalism/abuse surface;
  unnecessary given the geometry (FMEA F7).
- Self-locking chain holds everywhere without power: simplest, satisfies "stay
  closed", but sustains a pin on power loss (F3). Rejected.
- Motor-side declutch on power loss: does NOT work — the rigid chain's self-lock is
  intrinsic and downstream of the motor, so it would still hold the pin. Pin relief
  must come from a back-drivable OUTPUT, not a motor clutch.
- Fully back-drivable + powered brake to hold closed: a powered / fail-applied brake
  either needs standby power or re-creates the held-pin problem. Rejected in favour of
  the passive flush latch.

**Accepted costs / constraints / to verify.**
- Gives up the zip-chain's zero-power holding mid-stroke and at deployed; holding
  during operation is by a powered brake + end stops, at-rest-closed by the latch.
- Adds the flush latch as a new part: must be reliable and self-tested; its powered
  release must fail safe (release fails -> pod stays closed -> safe, since no occupant
  can be inside a flush pod; an availability cost only).
- **Seal drag vs. passive relief — CHECKED (`scripts/pin_relief.py`, first-order).**
  Back-drive stalls when the tissue reaction equals the seal drag, so the residual pin
  floors at the resisting force ~1.2 kN — about **12x** a safe sustained contact force
  (100 N, ADR-0024). **Passive relief alone is INSUFFICIENT.** Therefore a stored-energy
  return element (~1.5 kN spring / gas strut biasing toward deployed, held off by the
  flush latch at close) is **required** to unload the occupant — at a cost of ~2.3x the
  closing design force (2411 -> ~5546 N). Reducing seal drag enough (<=~10.6 N/m, a >14x
  cut) is not credible for a lip seal. Alternative worth exploring: a seal that sheds
  its drag on power loss (relaxes / retracts) so passive back-drive suffices. Confirm
  with real tissue + seal-drag data before freezing.
- Verify the rigid-chain actuator is genuinely back-drivable in the occupant zone
  (link/tooth geometry); if not, an output-side release clutch is required there.
- The latch engagement zone must be provably past any occupant presence (final flush
  mm only); the SF2 safety edge covers the final-approach pinch (H8).
- Supersedes the tentative options (a)/(b) sketched in SAFETY.md's FMEA note.

**Follow-ups.** Add the return element (~1.5 kN) to the drive concept and re-run
actuator sizing with the higher closing force; or investigate a power-loss
drag-shedding seal as an alternative. Model the latch + back-drive path in CAD once
the mechanism is chosen. Confirm the pin-relief numbers with real tissue/seal data.

---

## ADR-0010 — Actuator: single-acting tension-close + spring-open (supersedes ADR-0008)
**Date:** 2026-07-21
**Status:** Proposed (supersedes ADR-0008 if accepted). **Architecture de-risked
against the seal-drag unknown (2026-07-23, `scripts/seal_drag_sweep.py`): the
number sets the *sizing*, not the *choice* — see "Sensitivity" below.**

**Context.** ADR-0008 chose rigid-chain for three reasons: shallow install depth,
self-locking hold without power, and compactness. Two later decisions moved the goal
posts:
- **ADR-0009 (SF4)** requires the drive to be BACK-DRIVABLE in the occupant zone (fail
  open on power loss so a pin relieves), and moved holding-closed to a passive flush
  latch. So self-locking is now a *liability*, and the drive need not self-lock at all.
- **`pin_relief.py`** showed passive relief needs a ~1.5 kN stored-energy RETURN
  element biasing toward deployed. Sizing (`actuator_sizing.py`) shows that spring
  already drives the whole opening stroke (opening resist -362 N) -- i.e. a full-stroke
  deploy actuator now exists for safety reasons regardless of the drive choice.

Net: rigid-chain's self-locking advantage is gone (unwanted); only shallow depth
remains, which other architectures also achieve.

**Decision (proposed).** A SINGLE-ACTING drive: a tension member (toothed chain/belt
or cable) that only PULLS the piston closed, with the SF4 return spring PUSHING it
open.
- Closing: a powered drum/sprocket winds the tension member in, fighting seal drag +
  the return spring (~5.5 kN design, `actuator_sizing.py`).
- Deploy: the return spring drives the piston out; the drive brakes/controls a damped
  descent.
- Holding: passive flush latch (closed) + hard stop (deployed); powered tension holds
  mid-cycle.

**Why.**
- **Fail-open by nature (ADR-0009).** A tension member cannot push. On power loss it
  goes slack and the spring deploys the piston, relieving a pin -- no clutch, no
  self-lock to defeat. Checked: 1567 N spring vs 1206 N resist => net +361 N, unloads
  to zero contact.
- **Reuses the mandatory SF4 spring as the opener** -- the safety element and the
  deploy actuator are the same part (fewer parts, not more).
- **Shallow install depth** -- a drum/sprocket is as compact as the chain magazine, so
  rigid-chain's one surviving advantage is retained.
- **Simple / cheap / robust** -- chain-in-tension + drum is well-understood tech vs. a
  niche rigid chain.

**Rejected alternatives.**
- Rigid-chain (ADR-0008): self-locking is now unwanted (must be forced back-drivable or
  given an output clutch); its holding advantage is superseded by the flush latch. Only
  shallow depth remains, which this option also achieves.
- Ball / lead screw + motor: retract length ~ full stroke => deep install (what
  ADR-0008 avoided); strongly self-locking (wrong way for fail-open).
- Hydraulic cylinder: fail-open is easy (dump valve) but needs a stroke-length barrel
  (deep) and adds fluid/leak/freeze/hygiene problems for an outdoor unattended unit.
- Double-acting rigid drive + separate safety spring: more parts than folding the
  deploy into the mandatory spring.

**Accepted costs / constraints / to verify.**
- Softer position control on a tension drive (cable stretch). Mitigate with a toothed
  chain/belt (positive engagement); end stops + latch define the travel ends, and
  mid-stroke precision is not critical for this slow motion.
- The return spring stores ~3.4 kJ over the 2.2 m stroke (1567 N x stroke). Deploy MUST
  be damped -- the piston cannot slam open. Size a damper; a gas strut gives spring +
  damping in one.
- Single-acting: if the spring fails, the pod won't deploy -> stuck CLOSED. Fails safe
  (no occupant can be in a flush pod) but is an availability cost; the spring becomes a
  reliability-critical item (inspect/monitor).
- Closing design force ~5.5 kN on the winch/sprocket (x2 factor) -- verify the
  drum/motor/gearing and the tension member rating.
- Verify the drum freewheels/back-drives on power loss (not self-locking; a
  fail-released brake, not a fail-applied one).

**Sensitivity to seal drag (2026-07-23, `scripts/seal_drag_sweep.py`).** Seal drag is
the master unknown (~16–700 N/m; SF3/ADR-0011). Sweeping it through the same force
model as `actuator_sizing.py` / `pin_relief.py` shows the *architecture* is robust and
only the *sizing* moves:
- **Passive fail-open relief is safe only below ~13 N/m**, and the credible range
  *starts* at ~16 — so the SF4 return spring is mandatory across essentially the whole
  range. ADR-0009 isn't marginal, and ADR-0010's premise (reuse that mandatory
  full-stroke spring as the opener) holds nearly everywhere.
- **This decision therefore does not hinge on the measurement.** The measured number
  sets the *size*: design force swings ~60× (437 N at 10 N/m → ~25.6 kN at 700 N/m),
  spring energy 0.3 → 16 kJ. Spring-open + tension-close stays the right shape.
- **Rework trigger: ~300 N/m.** Above it, forces are 2–4× the model and the design must
  change (cut interference, drop to one lip, or change seal tech) rather than just
  resize the drive. So the bench test is also a go/no-go on the 2-lip / 3 mm design.
Practical read: accept ADR-0010's architecture now; leave the drum/motor/spring/damper
*sizing* open until the bench test (`docs/seal_drag_bench_test.md`) returns a number,
then read it against the sweep table.

**Follow-ups (if accepted).** CAD: replace ChainMagazine/ChainColumn with a drum +
tension member + return spring + flush latch; re-export to the twin. Update the
component tree. Add a damper spec. Re-confirm force/energy with the real spring rate.

---

## ADR-0011 — Specify a low-friction seal (seal drag is the master design lever)
**Date:** 2026-07-21
**Status:** Accepted

**Context.** Seal drag is the dominant load and, via `pin_relief.py`, sets the SF4
residual-pin floor (passive relief stalls when tissue reaction == seal drag). It
therefore couples SF3 (the seal), SF4 (return spring / fail-open) and the actuator
size. `seal_drag.py` (first principles, researched dry rubber-steel mu ~1.0-1.4) puts
the credible range at ~16-700 N/m; the 150 N/m working assumption is a mid value, and
a dry gritty street lip trends toward the HIGH end.

**Decision.** Make LOW seal friction a hard requirement for SF3: specify a low-friction
wiper (PTFE-faced / lubricated / brush), minimise lip count and interference, and
MEASURE the drag on a real sample before freezing any force numbers.

**Why (quantified, `SEAL_DRAG_PER_M` = 40 vs 150 N/m).**

| metric | 150 N/m (dry lip) | 40 N/m (low-friction) |
|---|---|---|
| resisting force | 1206 N | 333 N |
| passive residual pin | 1206 N (~10x safe) | 333 N (~3x safe) |
| SF4 return spring | 1567 N | 433 N |
| closing design force | 5546 N | 1532 N |

Everything scales ~3.6x down. The spring's stored energy (the deploy-slam hazard)
falls with it (~3.4 kJ -> ~0.95 kJ), easing the damper. Low friction does NOT remove
the spring (passive-only-safe needs <=~13 N/m, i.e. near-frictionless), but it shrinks
the whole SF4 + actuator apparatus from heavy to modest.

**Rejected / not chosen.**
- Aggressive dry elastomer lip (best wiping/hygiene): trends to the high end of the
  drag range -> huge actuator + spring. Rejected as the primary sealing approach.

**Accepted costs / to verify.**
- A low-friction (PTFE / lubricated / brush) wiper may scrape LESS aggressively --
  check hygiene + grit exclusion; may need a two-stage soft-scraper + low-friction
  seal, with the drag budget counting both stages.
- Lubrication in an unattended street unit: dry-film / grease retention, contamination.
- MEASURE drag on a real sample (dry, with grit). This one number gates the actuator,
  the SF4 spring, and whether ADR-0010's drive complexity is even warranted.

**Follow-ups.** Once measured, re-run `pin_relief.py` / `actuator_sizing.py`
(`SEAL_DRAG_PER_M=<n>`) and revisit ADR-0010 -- a small spring + light actuator may
simplify the drive choice.

---

## ADR-0012 — SF1 occupancy sensing: diverse-redundant, fail-safe, PL e
**Date:** 2026-07-22
**Status:** Accepted (architecture + PL target); sensor part numbers + certification TBD

**Context.** SF1 (occupancy detection) is the PRIMARY safeguard -- PREVENT: never move
while occupied (H1/H6); the whole safety case leans on it. Users are assumed VULNERABLE
and may NOT self-rescue, so a missed occupant can be fatal. The twin has fail-safe
*voting logic* (`safety_interlock.gd`) but no physical sensor suite, redundancy
architecture, or performance level. This ADR fixes those.

**Decision.**
1. **Target ISO 13849-1 PL e, Category 3-4.** Risk graph: S2 (death) + F2 (occupant
   present for hours) + P2 (vulnerable, scarcely able to avoid) => PLr = **e**. The
   safety function "presence detected => motion inhibited" runs on a rated safety
   controller (dual-channel / safety PLC), not the ordinary control MCU.
2. **Diverse-redundant sensor suite** (different physics, so no single common-cause
   failure can blind it):
   - **A. mmWave / UWB vital-sign radar (primary)** -- respiration + heartbeat
     micro-motion on a MOTIONLESS person; penetrates clothing / blanket / sleeping bag.
     Catches the still, cold, covered occupant the others miss (e.g. 60 GHz FMCW).
   - **B. Thermal IR array** -- body-heat signature/shape. Supportive; weak on a
     hypothermic occupant, so never sole.
   - **C. NDIR CO2** -- exhaled-CO2 rise = metabolism. Independent physics,
     penetration-independent (works under a blanket), slow.
   - **D. Floor load cells + ballistocardiography** -- static mass = something present;
     micro weight-shifts from pulse/breathing = alive. Threshold low enough for a small
     animal.
   - (Optional E: mouth-plane light-curtain / ToF for external reach-in during motion,
     H5.)
3. **Fail-safe voting** (matches the sim reference):
   - **OR toward life** -- ANY credible presence/life channel => occupied => inhibit.
   - **AND toward clear** -- motion only when ALL channels agree "empty" for a dwell
     (covers breath-hold / apnea).
   - **Fault = occupied** -- any channel faulted, stale, out-of-range, or disagreeing
     beyond tolerance => occupied. Absence of proof of emptiness is never "empty".
   - **Diversity for common cause** -- RF + IR + chemical + mechanical fail differently
     (dust/fog blinds optical but not radar/CO2/load).
4. **Must catch a small animal, not just an adult** -- radar/CO2/load thresholds tuned
   down; ambiguity (mass with no life signs) errs to possibly-occupied => hold.

**Why.** No single sensor sees the worst case (motionless, cold, blanketed, maybe a
small animal). Diverse redundancy + OR-toward-life + fault-is-occupied is the only way
to reach PL e for a may-not-self-rescue occupant. The sim already encodes the LOGIC;
this ADR fixes the PHYSICS and the RATING.

**Rejected alternatives.**
- Single sensor (PIR or a weight mat alone): common-cause blind spots -- a motionless
  person defeats PIR, a bag fools weight-only. Cannot reach PL e.
- Camera + vision AI as the primary channel: opaque failure modes, privacy (people
  sleeping), poor in dark / under a blanket, hard to certify to PL e. At most auxiliary.
- "Possibly occupied => push out slowly": ruled out project-wide (SAFETY.md).

**Accepted costs / to verify.**
- Cost/complexity of 4 diverse channels + a rated safety controller -- justified by
  S4 / PL e.
- Validate radar vital-sign range/reliability through bedding, multi-occupant and
  small-animal sensitivity, on real hardware.
- Sensor placement / field-of-view: no dead zones in the bore; radar EMC in a metal bore.
- Privacy: prefer non-imaging sensors (radar / CO2 / load / thermal-array) over cameras.
- Formal PL e verification (category, MTTFd, DC, CCF per ISO 13849-1) once parts chosen.
- Dwell time vs. apnea / breath-hold: set from clinical data.

**Modelled (2026-07-23).** The diverse-redundant voting is now a real module,
`godot/occupancy_fusion.gd` (four channels: radar vitals / thermal / NDIR CO2 /
load-BCG), replacing the stub OR in `safety_interlock.gd` (which now consults the
fusion when attached). It encodes the three fail-safe rules — OR-toward-life,
fault=occupied (unhealthy / out-of-range / stale), AND-toward-clear — and a runtime
`self_test()`. The headless test `godot/tests/test_occupancy_fusion.gd` fault-injects
each channel/mode, checks the diversity cases (hypothermic-covered occupant; static
mass with no life signs; fully blinded suite), and exhaustively verifies the invariant
across all 3⁴ vote combinations: "empty" only when **every** channel positively reads
clear. This is `[sim]` — logic + rating, still no physical sensors.

**Follow-ups.** Choose sensor part numbers; optionally surface the per-channel votes in
the visual twin (`physics_demo`); build the PL e verification dossier (category, MTTFd,
DC, CCF per ISO 13849-1) once parts are chosen.

---

## ADR-0013 — Sitting-height mouth: accept single-layer fall protection (H4)
**Date:** 2026-07-22
**Status:** Accepted (risk acceptance — needs a named sign-off at commissioning)

**Context.** H4 = fall from an elevated mouth. The prior siting rule was "mouth at floor
level, or guard it", so a person swept toward the mouth in an SF1 fault cannot also
fall. But a floor-level sill lets ejected inanimate items pile right at the opening
(bad for the clearing function + hygiene). A sitting-height sill (~450–500 mm) makes
ejected items fall *clear*, and suits sit-and-swing entry.

**Decision.** Set the mouth sill at ~sitting height (~450–500 mm). Accept that this
removes the floor-level fall protection: H4 fall protection now rests SOLELY on SF1
(never move while occupied) — a deliberate single-layer choice for this one hazard.

**Why accepted.**
- SF1 is diverse-redundant, fail-safe, PL e (ADR-0012) with the independent SF2 contact
  backstop, so a push-out needs several independent failures (low probability).
- The residual fall is low — ~450–500 mm, roughly a high step, not a fall from height
  (H4 is S3, not S4).
- Real function benefit: items fall clear instead of jamming the sill; better hygiene;
  natural entry.
- Physical reality: any edge debris falls off, a limp person could fall off too — a
  floor-level sill was the only way to get BOTH object-clearing and no drop. We chose
  object-clearing.

**Rejected alternatives.**
- Floor-level sill + walkable grated recess / catch tray: keeps the H4 layer AND
  object-clearing (debris drops through a grate; a person is supported). The safer
  option; not chosen, in favour of the simpler sitting-height opening.
- Sitting sill + same-level guarded landing + person-excluding grate: preserves the
  layer but more complex; not chosen.

**Accepted costs / constraints (bounds on the trade).**
- Fall protection is now SINGLE-LAYER (SF1) — a conscious exception to the project's
  "never the sole defense" principle, logged not overlooked.
- The accepted drop is ~500 mm ONLY: do not stack cells so a mouth opens over a real
  drop; upper tiers still need a same-level access gallery.
- Require a forgiving, non-slip drop-zone + collection tray below/in front of the mouth.
- Needs a NAMED risk-acceptance sign-off at commissioning; confirm sill height +
  drop-zone against local building code.
- Validate the ~500 mm residual against human-factors data for a NON-REACTING person (a
  limp fall differs from a stumble) — the one soft number in this trade.

**Follow-ups.** SAFETY.md Siting rules + H4 row carry this; obtain the sign-off; HF check
on the limp-fall residual.

---

## ADR-0014 — Interior lighting: warm, blue-depleted, occupancy-staged, top status
**Date:** 2026-07-23
**Status:** Accepted

**Context.** The cell needs interior light to (a) let a user orient on entry and while
inside, and (b) show status — without (c) preventing sleep. The users are vulnerable
(asleep / intoxicated / unwell) and can't self-rescue, inside a sealed steel cavity.
Fixed constraints: vandal resistance, hygiene (must survive the cleaning sweep +
washdown), low energy, and NO interior user-accessible controls (ADR-0009). The three
jobs pull against each other — light-to-see vs dark-to-sleep vs be-noticeable.

**Decision.** A single warm, blue-depleted (≤2200 K / amber), flicker-free luminaire,
recessed FLUSH into the crown (top) of the fixed barrel and running along the bore.
Levels are occupancy-staged off SF1: on entry a brief orientation level (~20–50 lx),
then a settled night-glow (~1–5 lx) held for the whole stay. The luminaire *is* the
interior status indicator, by colour, but only while the pod is EMPTY — available =
green, in-movement = red; the instant it is occupied it holds warm amber. An always-lit
warm line marks the mouth threshold (egress) whenever occupied. "Closed" is not shown
inside (self-evident once the piston face is the exterior wall).

**Why.**
- **Top / crown mount:** a lying body or bedding can't cover it, and the piston's top
  wiper cleans it every sweep. Flush → no gap that would raise seal drag (SF3 / ADR-0011).
- **Warm + blue-depleted + very low lux at rest:** minimal melanopic (melatonin) load,
  so it doesn't block sleep. A large diffuse strip = low *luminance* → no glare even
  though it is overhead (luminance dazzles, not lumens).
- **Colour status only while empty:** green/red never fall on a sleeper; the occupancy
  state itself switches the fixture from "signal" to "warm glow".
- **Night-glow + egress marker are SAFETY, not comfort:** a pitch-black sealed steel box
  for an intoxicated/unwell person invites panic, hides whether they have been sick, and
  buries the only exit — the same non-self-rescue logic that drives SF1/SF2.
- **Interior placement** keeps it cleaned by the sweep and is separate from the external
  **SF5 beacon** (which still warns the PUBLIC face before motion) — two audiences.

**Rejected alternatives.**
- Floor / side mount: coverable by a body or bedding; not cleaned by the top wiper.
- Fixed brightness: cannot satisfy see-on-entry AND sleep at once.
- Cool/neutral white, or a bright status colour while occupied: melatonin suppression +
  glare on the sleeper.
- Occupant dimmer / any interior control: a tamperable, hygiene-trapping actuable that
  conflicts with ADR-0009 (no interior release/controls). Staged auto-levels instead.

**Accepted costs / constraints.**
- Small standby energy for the always-on night-glow (bounded: one low-output warm LED
  strip, order a few hundred mW).
- The diffuser must survive repeated wiper contact + washdown — sealed, impact-resistant,
  flush; a defined maintenance item.
- Spectral/level targets (≤2200 K; ~1–5 lx rest, ~20–50 lx entry; melanopic EDI TBV) are
  first-pass — validate against sleep/circadian + wayfinding human-factors data.
- Flicker-free (no visible temporal light modulation): DC / constant-current drive.

**Follow-ups.** SAFETY.md carries the night-glow + egress marker as occupant protection
for non-self-rescue. CAD adds a flush crown `Luminaire` part (build_model.py); the twin
and the render show the state→colour + warm glow. Confirm melanopic EDI + lux targets
with a photometric spec.

---

## ADR-0015 — Cleaning: motion-driven wash-in-transit + thermal-chemical sanitize, plumbed
**Date:** 2026-07-27
**Status:** Accepted (architecture + method); part selection, sizing, sewer-discharge
compliance and freeze design TBD. Specifies the deferred component-tree item 6.
**Revised by ADR-0016** — the exterior mouth rinse bar + drop tray (points 4 / 5a) and the
internal FloorDrain are removed for vandal resistance; everything exits the mouth to a
flush pavement trench drain instead.

**Context.** Until now "cleaning" was only the piston's dry wiper sweep (ADR-0001):
mechanically squeegee the bore and eject loose solids out the mouth. The real cleaning
subsystem was deferred ("reserve mounting bosses and space claim"). Users are assumed
intoxicated / unwell / vulnerable, so the design case is **bodily fluids every cycle**,
not dust — a dry wiper cannot sanitize, cannot remove fluid films, and just smears
biofilm. Two topology facts drive the whole design:
1. The **piston face** is both the occupant's backrest AND the flush public wall
   (ADR-0001). It is public-side when closed (street grime, graffiti, ejected splatter)
   and interior when open — it swaps a contaminated exterior surface straight onto the
   next sleeper.
2. The **mouth sill / bottom lip** catches everything swept out (ADR-0013 drop tray).
Both are on the **public** side and are **never inside a sealed chamber**, so a flooded
"seal the service side and wash the box" CIP reaches the bore walls but never the two
dirtiest surfaces. Siting assumption (new): the unit is plumbed to **city mains water +
sewer**, so wet wash + drain is available (vs a self-contained tank).

**Decision.** Design for the worst case (fluids every cycle) with a **motion-driven
"wash-in-transit"** subsystem — fixed cleaning stations the piston sweeps *past*, using
its own stroke as the motion — not a flooded CIP box. Sanitize is **thermal + chemical**.
1. **Debris (existing).** The closing sweep ejects big items out the mouth to the tray,
   so interior residual is **liquids + fines only → no macerator** on the drain.
2. **In-bore wash / squeegee ring (fixed station).** The piston face and bore walls pass
   through it every stroke: pre-rinse → dosed detergent → **82–90 °C hot-water/steam
   sanitize** → **metered chemical disinfectant** → full-perimeter squeegee. Runoff to a
   sloped floor + drain port → sewer.
3. **Thermal + chemical sanitize.** Hot water/steam covers most pathogens; a **metered
   disinfectant dose** closes the spore gap (*C. diff* / norovirus) that thermal alone
   misses — justified by the every-cycle vulnerable-user case. Chemical is a refill
   consumable.
4. **Mouth rinse bar + flushed sloped tray.** A rinse bar at the mouth lip washes the
   sill; the ADR-0013 drop tray becomes a sloped, flushed catch basin → same sewer line.
5. **Pre-present purge + dry choreography (on open, before the next guest):**
   a. **Crack open** ~a piston-width; the rinse bar cleans the exposed exterior
      face-edge + mouth.
   b. **Close** to squeegee/push it all out over the sill into the tray → drain
      (repeat 1–2× as agitation).
   c. **Open a second time with a drying dwell** — pause partly open at a drying station
      (warm-air knife + the squeegee ring) to dry the face and near-bore, **then** open
      fully. Presents the cell **clean and dry**.
   The deep clean happens on the previous guest's **close**; the purge + dry-dwell happen
   on **open**, so the face is cleaned *on the way in, every time* and street grime picked
   up while closed can never reach an occupant. The small aperture + immediate squeegee-out
   make the purge **self-containing** — no wet cell is ever fully exposed to the street.

**Why.**
- **Worst-case fluids demand wet wash + sanitize + dry.** A dry sweep can't do any of the
  three; this is priority #2 (hygiene) for a non-self-rescue user.
- **Wash-in-transit reaches what a sealed CIP can't** — the piston face and near-mouth
  band — by reusing the existing stroke. Few added parts (fixed nozzles, squeegee ring,
  rinse bar) keeps faith with simplicity/reliability/cost.
- **The purge cleans the two public-side surfaces right before presenting**, and is
  contained by choreography rather than by adding a shroud.
- **Thermal + chemical** — heat is cheap and logistics-free and kills most pathogens; the
  chemical dose covers spores for the worst case. Plumbed mains+sewer makes both viable.

**Rejected alternatives.**
- **Pyrolytic burn-to-ash (self-cleaning-oven, ~480 °C):** heats a ~2 m steel bore every
  cycle (kills priority #5/#7); destroys the wiper seals, crown luminaire (ADR-0014) and
  the radar/thermal/CO2/load occupancy sensors (ADR-0012); thermally warps the 3 mm
  running fit; emits smoke/VOCs on a public street; and the heat-up/cool-down wrecks
  turnaround. Heat is retained only as **thermal sanitization (≤~90 °C)**, never
  incineration.
- **Flooded sealed-chamber CIP only:** cannot reach the piston face or the mouth sill.
- **Dry mechanical sweep only (status quo):** no sanitize; smears fluids/biofilm.
- **Waterless (UV-C / consumable liner) only:** UV-C is line-of-sight (shadowed by soil),
  degrades seals/diffuser, and removes no fluid; liners need restocking (not unattended).
  UV-C survives only as an optional dry finisher.
- **Interior macerator:** unneeded once the sweep ejects big items first.
- **Thermal-only sanitize:** misses spores; rejected for the every-cycle worst case.

**Accepted costs / constraints / to verify.**
- **Material spec (hard, new).** Every wetted part — wiper seals (SF3), luminaire diffuser
  (ADR-0014), sensors behind splash gaskets — must tolerate **~90 °C + water + detergent +
  disinfectant, repeatedly**. Constrains SF3 and ADR-0014.
- **Chemical = a consumable.** Breaks pure unattended operation: a disinfectant reservoir
  to refill + monitor. Dosing must **fail safe** — empty/failed dose ⇒ flag + fall back to
  thermal, never report "sanitized".
- **Sewer discharge compliance.** Disinfectant + wash effluent must meet municipal
  trade-effluent limits (dilution/neutralization) — a permitting item.
- **Seal wear / drag budget (ADR-0011).** The purge (1–2×) and wash strokes add wiper
  passes over the bore; bound the cycle count and add it to the seal-life + drag budget.
- **Drying is mandatory** (no wet backrest): warm-air knife + squeegee ring; the air
  heater adds energy — bound it.
- **Safety at the mouth.** Crack-purge strokes are in the near-flush **no-occupant** zone
  (ADR-0009), but a reach-in is possible ⇒ the **mouth-plane presence sensor** (ADR-0012
  optional channel E) is **promoted to required**, with the SF2 safety edge and an SF5
  "cleaning — stand clear" signal. Gate the exterior rinse on presence.
- **Freeze protection.** Outdoor unit: trace-heat / self-drain the exterior nozzles, tray,
  mains and drain.
- **Water + energy per cycle.** Quantify liters (in-bore wash + 1–2 purges + hot sanitize)
  and heater energy; challenges priority #5 (low energy), accepted for hygiene #2.
- **Backflow prevention** on the potable mains connection.
- **Space claim / install depth.** Nozzles, manifold, heater/steam gen, disinfectant
  reservoir + doser, dry-air blower and drain must fit the service chamber; update the
  depth budget (ADR-0007/0008/0010).

**Follow-ups.**
- **CAD (`build_model.py`):** add space-claim parts — in-bore spray ring (SprayRing), mouth
  rinse bar, sloped floor + drain port, disinfectant reservoir + doser, heater/steam
  generator, dry-air blower/knife; convert component-tree #6 bosses from "reserved" to
  real geometry; re-export to twin (add to `PARTS`, ADR-0006).
- **Safety:** promote ADR-0012 channel E (mouth-plane presence) to required; SF5 add the
  cleaning-cycle signal; SAFETY.md carry the wash/purge hazards + water-on-public.
- **Materials:** 90 °C / wet / chemical-tolerant seals, diffuser, gaskets (SF3, ADR-0014).
- **Analysis:** water + energy + chemical per cycle; sewer-discharge compliance; freeze.
- **Twin / render:** the digital twin and the cinematic S3 should depict this exact
  choreography (crack → purge → close → open-with-dry-dwell → full open) — the film's
  "cleaning" is now grounded in a real mechanism, not an invented glow.

---

## ADR-0016 — Cleaning stays off the public face; everything exits the mouth (revises ADR-0015)
**Date:** 2026-07-27
**Status:** Accepted. Revises ADR-0015 points 4 and 5a and its internal FloorDrain.
**Drainage refined by ADR-0017** — the wash media (hot water + chemicals) drains to an
internal piston-hidden back sump, not out the mouth; only gross solids exit to the grate.

**Context.** ADR-0015 put two cleaning parts on the STREET face — a mouth rinse bar and a
drop tray under the opening. Both are exposed even when the cell is closed, so they are
grab-able / smashable / trash-able: they violate design priority #1 (vandal resistance),
the very reason the closed cell is otherwise just a flush, handleless, latched steel face.
A tempting fix — capture the debris on the SERVICE side — was rejected because it breaks
the machine's core invariant: the cell **pushes everything OUT the mouth and traps
nothing; the service side is always sealed** (ADR-0001; the occupant is always mouth-side
of the piston, ADR-0009). Debris cannot cross the piston seal into the sealed chamber.

**Decision.** Keep the push-out invariant and take ALL cleaning hardware off the public face.
1. **Everything exits the mouth.** Solids AND wash water leave via the mouth; the bore
   floor **slopes toward the mouth** (no internal low-point drain to clog or trap). The
   ADR-0015 internal FloorDrain is dropped.
2. **A flush pavement trench drain, not an appendage.** A grated, load-rated channel set
   into the PAVEMENT at the mouth base takes the ejected solids + runoff straight to sewer.
   It is streetscape infrastructure — bolted, walk-on, flush — with the solids interceptor
   serviced from **below / behind (a manhole)**, never from the street face. (CAD part
   `TrenchDrain`.)
3. **No mouth rinse bar, no hanging tray.** The interior `SprayRing` cleans the mouth /
   sill / exterior face-edge during the crack-open purge; the runoff drains back out the
   mouth into the trench. If a dedicated mouth rinse is later needed it is **flush jets
   recessed in the sill frame**, not a protruding bar.
4. **Closed = flush face only.** The public sees the hardened piston face; the sole other
   street element is the bolted pavement grate.

**Why.** Priority #1: nothing fragile or grab-able on the public face. The trench is
infrastructure-grade (a city gutter / trench grate), effectively unvandalizable. It keeps
the push-out / never-trap invariant and the sealed service side intact, and it is simpler
(three cleaning parts, not five).

**Rejected alternatives.**
- **Service-side / internal debris capture:** violates the sealed-service, never-trap
  invariant (ADR-0001 / 0009) — debris would have to cross the piston seal. Rejected.
- **Hardened rinse bar / tray on the wall face:** still a street-face target; a flush
  pavement drain is strictly better.

**Accepted costs / to verify.**
- Siting now needs a **plumbed pavement trench + sewer tie** at the mouth, a load-rated
  walk-on grate, and freeze protection (trace-heat / self-drain).
- The **solids interceptor** basket is a maintenance item, reached from below.
- Confirm the bore-floor slope fully drains to the mouth and does not pool at the sill.
- Biohazard runoff crosses the pavement only at the mouth base before dropping through the
  grate — keep the trench hard against the mouth; confirm splash / hygiene.
- **Revisits ADR-0013:** the "drop zone / collection tray" is now this trench drain; the
  sitting-height sill (object-clearing) rationale still holds — items fall into the trench.

**Follow-ups.** CAD: drop `MouthRinseBar` + `DropTray` + `FloorDrain`, add `TrenchDrain`,
slope the bore to the mouth; re-export + update the anatomy diagram. SAFETY.md: note the
pavement drain + slip / hygiene. Confirm grate load rating + trench sewer tie at siting.

---

## ADR-0017 — Wash media drains internally via a piston-hidden back sump (refines ADR-0016)
**Date:** 2026-07-27
**Status:** Accepted. Refines ADR-0016 drainage; reinstates an internal drain (done right).

**Context.** ADR-0016, chasing vandal resistance, routed EVERYTHING out the mouth —
including the wash liquids. But the wash media is hot water + detergent + disinfectant;
sheeting hot chemical water across a public sidewalk (even onto a grate) is worse than the
street hardware it avoided. The wash media needs a proper, contained drain to sewer.

**Decision.** SPLIT the drainage by what it is:
1. **Gross solids** still ride the closing sweep OUT the mouth to the flush pavement grate
   (`TrenchDrain`) — solids can't cross to the sealed service side (ADR-0001 / 0009) and
   would clog an internal drain.
2. **Wash media (hot water + chemicals)** drains INTERNALLY to a **back sump** (`SumpDrain`)
   → sewer; the bore floor slopes to it. Hot chemical water never reaches the street.
3. **The sump is hidden UNDER the piston when it is deployed to the very back** (Eddy's
   refinement). It is covered by the piston when the cell is OPEN — so there is never a
   grate in the occupied cavity (no tamper point, no debris trap, hygienic) — and it is
   behind the flush face when CLOSED. The public and the occupant never see it. So the
   internal drain is *more* vandal-resistant than a street feature, not less.

**Why.** Keeps ADR-0016's principle (no cleaning hardware on the public FACE) while giving
the hot / chemical wash a correct, contained path to sewer. Hiding the sump under the
deployed piston removes the only downside of an internal floor drain — an exposed grate in
the occupied space.

**Rejected alternatives.**
- **Everything out the mouth (ADR-0016 as written):** dumps hot disinfectant water on the
  pavement. Rejected.
- **Exposed floor drain in the occupied cavity:** tamper point, debris trap, hygiene risk.
  Rejected for the piston-hidden position.

**Accepted costs / to verify.**
- The wash choreography must actually deliver the media to the back sump: confirm nozzle
  placement (SprayRing + any deep jets) and the floor slope so the media reaches the sump
  in whatever piston position the wash runs. Space-claim reserves the sump; the hydraulic
  detail is TBD.
- Sump strainer / interceptor serviced from below; sewer tie + trap + freeze protection.
- The sump sits under the deployed piston body (X ≈ cavityLength..barrelLength); confirm it
  clears the piston + actuator and drains fully.

**Follow-ups.** CAD: `SumpDrain` added (space claim); slope the bore to it; re-export +
update the anatomy diagram. SAFETY.md: hot-water / chemical drain to sewer + trap.

---

## ADR-0018 — Two spray rings: front (past the closed piston) + a hidden service-side ring
**Date:** 2026-07-27
**Status:** Accepted. Resolves the ADR-0017 "nozzle placement" to-verify.

**Context.** The wash must reach the surfaces the occupant touched — which end up in the
SEALED CHAMBER behind the piston when the cell is CLOSED (X > ~300; the piston body is
~300 mm wide). A single spray ring near the mouth (ADR-0015, at X=40–120) sits INSIDE that
closed-piston zone, so it can only hit the piston's side, not the chamber.

**Decision.** Two fixed spray rings, so the closed chamber is washed from both ends:
1. **SprayRing (front)** moves to just PAST the closed piston (X = pistonLength + 40 ≈ 340).
   Still near the mouth, but on the service side of the flush face, so it sprays the front
   of the sealed chamber — and the piston face still sweeps past it in transit for a rinse.
2. **ServiceSprayRing (deep)** sits BEHIND the deployed piston face (X = cavityLength + 60 ≈
   2260), so it is NEVER in the occupant space — never seen or reached by the user. It
   washes the deep end of the sealed chamber when the cell is closed.

**Why.** One ring can't be both within reach of the mouth AND past the wide piston; the two
requirements are ~2 m apart. Two rings, front + deep, cover the whole closed chamber, keep
the deep ring permanently hidden from the occupant, and the front ring doubles as the
in-transit face rinse.

**Rejected alternatives.**
- **Single mouth-side ring (ADR-0015):** buried in the closed piston; can't wash the chamber.
- **Single deep ring only:** would miss the piston face / front region and the in-transit rinse.

**Accepted costs / to verify.** Two nozzle manifolds + supply lines (more plumbing). The
deep ring shares the bore cross-section with the deployed piston body — confirm clearance.
Spray coverage/overlap along the 2.2 m chamber is still TBD (two stations may not be enough;
the sump slope must carry the media from both).

**Follow-ups.** CAD: SprayRing repositioned + ServiceSprayRing added (space claim);
re-export + diagram updated.

---

## ADR-0019 — Cleaning method: spray-and-squeegee + a traveling service-side squeegee
**Date:** 2026-07-27
**Status:** Accepted (method + component). Stow via option (b), a deeper chamber. Drive + wash
hydraulics TBD.

**Context.** With the spray stations set (ADR-0018), how does the wash actually clean the full
2.2 m bore and use the drain? Options surveyed: (1) fixed rings + the piston's own seals as the
squeegee; (2) many distributed rings; (3) nozzles on the moving piston; (4) flood-and-soak
immersion; plus a recirculating loop as a cross-cutting enhancement. The syringe already owns a
full-length squeegee — the piston's wiper seals — so coverage can come from MECHANICAL spreading,
not spray reach, favouring few stations (Option 1). But there's a gap: during the sealed-chamber
wash the piston is PARKED flush, so it can't traverse the chamber to scrub it.

**Decision.**
1. **Method = Option 1 (spray-and-squeegee).** The two fixed rings (ADR-0018) wet + dose + hot
   rinse; scrub + spread + drive-to-drain are done by wipers, not spray reach. A recirculating
   loop is added later only if coverage/sanitize proves marginal.
2. **Add a traveling service squeegee (`ServiceSqueegee`).** A wiper that runs the FULL sealed
   chamber while the piston is parked flush — a car wash over the stopped piston, scrubbing from
   inside the bore and driving the wash media to the sump. It lives ENTIRELY on the service side /
   hidden — never seen by the occupant, nothing on the public face.
3. **Stow via a deeper chamber (option b).** The barrel is extended by `squeegeeStow` (80 mm) so
   the squeegee stows behind the deployed piston when the cell is open. Cost: install depth
   2.86 → **2.94 m**. Chosen over (a) a thin disc in the actuator gap (too tight, fouls the chain)
   and (c) nesting it on the piston carrier (most mechanism).

**Cycle.** Close (eject solids out the mouth) → rings spray → squeegee traverses the chamber
scrubbing + pushing media to the sump → hot rinse + final squeegee pass → dry → open (squeegee
retreats into the stow bay behind the piston).

**Why.** Keeps the syringe-native squeegee idea but gives it a dedicated traveler, closing the
parked-piston coverage gap at full-length scrub quality for the worst-case hygiene case. Keeping
it service-side costs nothing in vandal resistance or occupant space.

**Rejected alternatives.** Distributed rings (#2): more penetrations/plumbing/service. Nozzles on
the moving piston (#3): a fluid line on the moving, occupant-contacting part. Immersion (#4): asks
a wiper seal to hold a water column; water/energy/drying/freeze. All revisitable if bench tests demand.

**Accepted costs / to verify.**
- A SECOND moving mechanism + its own light drive (fights only wiper drag, not seal pressure),
  hidden service-side. Against simplicity, bought for hygiene.
- +80 mm install depth for the stow bay (against the ADR-0008/0010 shallow-depth budget).
- The squeegee shares the bore axis with the central chain/rod — confirm the passage/clearance.
- Bench gates (from the survey): does the wiper spread + scrub a full-length film; is
  spray+squeegee+heat+chemical enough log-reduction or is immersion needed; water/energy per cycle;
  does gravity + squeegee actually clear the sump.

**Follow-ups.** CAD: `ServiceSqueegee` added, barrel extended (space claim); its drive is TBD.
Twin: a new mover (added to `moving_parts`) — animate its traverse. Re-export + diagram.

---

## ADR-0020 — Squeegee drive: a dedicated, swappable rigid-chain unit
**Date:** 2026-07-27
**Status:** Accepted (drive choice + space claim). Chain sizing, the offset→central coupling,
and the motor are TBD.

**Context.** ADR-0019's `ServiceSqueegee` needs its own drive. The syringe topology forbids
external rails / wall slots (ADR-0007), so the drive must be central/coaxial like the piston's.
Options surveyed: (1) water-driven "cleaning pig" + tether (reuses the wash pump, no motor);
(2) shared piston actuator + a drive-transfer clutch (one motor, but a fragile clutch);
(3) a dedicated compact rigid-chain (a second zip-chain, its own motor); (4) a central
lead/ball screw (whip + depth + wash-zone corrosion).

**Decision.** Option 3 — give the squeegee its OWN compact rigid-chain drive (`SqueegeeDrive`),
a modular unit that nests in the back-of-house BESIDE the piston's actuator (no added install
depth) and pushes the squeegee's back.

**Why.** Chosen for SERVICEABILITY / reliability (priorities #3 / #4 / #8): an independent module
that can be bench-tested and swapped on its own, decoupled from the piston drive — no shared
clutch to fail (rules out #2), no dependence on wash-pump pressure or a mostly-sealing disc
(rules out #1's soft force/positioning), no long whippy screw in the wash zone (rules out #4).
Rigid-chain is proven (ADR-0008) and the squeegee's load is light (one low-friction wiper), so
the unit is small.

**Rejected alternatives.** Water pig (#1): elegant and motorless, but soft force/positioning and
the disc must mostly-seal — revisit if the chain proves overkill. Shared clutch (#2): a transfer
dog is a reliability risk for an unattended unit. Lead screw (#4): whip + retract depth (the
problem ADR-0007 avoided) + wash-zone corrosion.

**Accepted costs / to verify.** A second motor + controller (against simplicity #7, bought for
serviceability). **Coupling:** the drive nests offset in +Y, so a yoke/arm must transfer its push
to the central squeegee ring **without a wall slot** — confirm the routing. Chain/motor sizing vs
the (light) wiper drag. The back-of-house cross-section grows to house it (depth unchanged).
An independent self-test + quick-swap mounting are needed to actually realise the serviceability win.

**Follow-ups.** CAD: `SqueegeeDrive` space claim added beside the actuator; coupling + chain
column TBD (resolved in ADR-0021). Twin: drive the squeegee's traverse from it. Re-export + diagram.

---

## ADR-0021 — Squeegee-drive coupling: an in-bore offset chain lane + rigid yoke
**Date:** 2026-08-02
**Status:** Accepted (routing + space claim). Yoke stiffness/anti-rack detail, chain sizing,
and the motor remain TBD.

**Context.** ADR-0020 chose a dedicated rigid-chain `SqueegeeDrive` nested OFFSET in +Y beside
the piston's central magazine, and parked the hard question: how does that offset drive push the
CENTERED `ServiceSqueegee` ring **without a wall slot** (ADR-0007 forbids breaching the sealed
barrel, and ADR-0007 also rules out external rails)? The piston's own rigid chain already occupies
the central axis of the whole chamber when the cell is closed, so the squeegee drive cannot be
coaxial with it.

**Decision.** Run the squeegee's rigid chain **INSIDE the sealed bore**, in an **offset +Y lane**
near the wall (`squeegeeChainOffsetY = 430 mm`, chain 60×60, wall at Y=500), and couple it to the
ring's +Y frame with a **short rigid yoke** (`SqueegeeYoke`). No slot, no gland, no wall
penetration. The bore itself guides the ring against rack (same principle as the piston in its
non-circular bore), so the push is applied on the +Y side only.

**Why it's sound (temporal exclusivity).** The piston (central) and the squeegee (offset) **never
occupy the chamber at the same time**, so they can share the one sealed volume at different times:
- **Cell open** → piston deployed into the chamber (X 0–2200); the squeegee + its chain + yoke are
  fully retracted to the stow bay behind the deployed piston (X ≥ 2500). The offset lane is empty.
- **Cleaning** → piston parked **flush at the mouth** (X 0–300); the whole chamber (X 300–2500) is
  sealed and free, and the offset chain extends down the +Y lane to sweep the squeegee across it,
  parallel to (and clear of) the piston's fully-extended central chain.
CAD confirms zero `CavityReference` intrusion for both the chain and the yoke (they stow at
X > cavityLength = 2200, behind the deployed piston) and that install depth is unchanged (2.94 m).

**Sizing (first pass, placeholder pending the wiper spec).** Wiped bore perimeter ≈ 3.98 m; a
single soft scrub lip (it does NOT seal — the piston does) at ~0.2 N/mm preload, wet-detergent
μ≈0.3 → drag ≈ 240 N; design to ~500 N with margin. Sweep 2.2 m at ~0.2 m/s → ~100 W mechanical,
sprocket torque ~24 N·m, ~40 rpm → a ~150–200 W gearmotor. Roughly an order of magnitude lighter
than the sealing piston actuator, confirming ADR-0020's "small unit / light load."

**Rejected / deferred.** A widened-wall chain channel with a traveling sealed gland (reintroduces
a slot — rejected). A two-point push bar spanning +Y to −Y (stiffer, no cocking, but crosses the
bore cross-section — deferred; revisit only if single-side push racks in test). The motorless
water-pig (ADR-0020) stays the fallback if the chain proves overkill.

**Accepted costs / to verify.** Single-side push relies on the bore as the anti-rack guide —
confirm the ring doesn't cock under wiper drag (else the two-point yoke). Chain column + motor
sizing vs the real wiper drag once the lip is specced. The +Y lane must stay clear of the deep
`ServiceSprayRing` (X 2260–2340) and the luminaire (top crown) — CAD clearance holds.

**Follow-ups.** CAD: `SqueegeeChain` + `SqueegeeYoke` added, offset +Y lane, stowed pose. Twin:
drive the squeegee's traverse along the lane. Re-export objs + update `docs/cell_anatomy.svg`.

---

## ADR-0022 — CLEARED_HOLD re-reads both safety trips (found by model checking)
**Date:** 2026-08-03
**Status:** Accepted. Implemented in the twin + spec; the availability cost is accepted as-is.

**Context.** The formal model added for roadmap #1 (`spec/`, TLA+/TLC) found a defect in
shipped interlock logic that neither the scenario self-test nor review had caught. The
`CLEARED_HOLD` branch of `safety_interlock.gd` — the dwell with the piston closed and flush
at the mouth — tested only `t >= hold_seconds`. It re-read **neither** SF1 nor SF2.

So a safety-edge trip at the flush position went unacted-on for the remainder of the dwell
(**2.0 s** at the twin's default). TLC reaches it by the route that matters: someone reaches
into the mouth (**H5**) at the exact position the piston is completing to, and is held
against the flush face. That is **H8**, the mouth-lip pinch — precisely the hazard SF2 exists
to answer. Every other state already reversed on either trip; this one state did not.

Bounded, not a crush: `Inv_NoCrush` held throughout (the piston never drives *past* the
occupant, and contact stays at the 120 N cap in effect at the time (revised to 100 N
under **ADR-0024**, sourced from injury/biomechanical data). The
defect is in the *latency* of the response, not its existence — but SF2's specification in
`SAFETY.md` says "immediate stop and reverse", and up to a full dwell is not immediate.

**Decision.** `CLEARED_HOLD` exits to `REDEPLOY` on `life_present() or contact_over_limit or
t >= hold_seconds` — either trip cuts the dwell short, matching what `CLEARING` already did.

**Why it's sound.** Reversing is the safe direction (the piston sweeps *away* from the
occupant, toward the open mouth), so an early exit is never worse than serving out the dwell.
There is no state in which staying flush longer is the safer choice: the "stay closed without
power" requirement is met by the passive flush latch (ADR-0009), which is unpowered and
unaffected by this path. Including SF1 as well as SF2 costs nothing and keeps the two trips
symmetric across every state — a fault now opens the pod rather than holding it closed, which
is the fail-safe direction.

**Accepted costs.** Availability, not safety: a spurious edge or channel reading at the flush
position now re-opens the cell instead of being ignored for ≤2 s. Judged the right trade for
an unattended public unit where the alternative is a bounded pinch at the mouth lip. If
nuisance re-opens show up in testing, the fix is a debounce on the trip, **not** restoring
the dwell.

**Follow-ups.** Done: twin (`safety_interlock.gd`), regression scenario S6 in
`test_interlock.gd`, spec `ClearedHold` + `Inv_NoTripHeldAtFlush` in `Safety.cfg`, and a
`hold-ignores-trips` mutant that re-injects the pre-fix code so the guard cannot silently rot.
`SAFETY.md` SF2 updated.

---

## ADR-0023 — The external E-stop is a Category 0 stop into the SF4 fail-open path
**Date:** 2026-08-03
**Status:** Accepted (behaviour + twin/spec implementation). Rated hardware + PL assessment TBD.

**Context.** ADR-0009 retained "an EXTERNAL / operator E-stop + remote tamper/fault
monitoring (availability, not a trap function)" but never said what pressing it *does*.
The twin had no E-stop input and no notion of drive power at all, so when the formal model
(roadmap #1) encoded SF4, its E-stop and power-loss claims were verified against *intent*
rather than against code — the one gap that verification effort left behind.

**Decision.** The E-stop **removes drive power** (Category 0, IEC 60204-1) rather than
commanding a controlled halt. It therefore enters exactly the same fail-open path as a
blackout, with ADR-0009's position-dependent behaviour: the return element relieves the
piston anywhere in the occupant zone, the passive latch holds the flush end. Releasing the
button does **not** restart anything — the machine backs out to deployed and re-enters the
cycle through `LIFE_CHECK`, so a fresh life-check must pass before the piston can advance.

**Why it's sound.** A "freeze in place" E-stop would recreate **FMEA F3** exactly: a
sustained pin with power gone and nothing able to detect or act (S4, D4 — the failure that
forced the whole SF4 design-out). It would be a deliberate mechanism for violating the one
requirement SF4 exists to enforce. Category 0 instead makes the E-stop *inherit* the
mitigation rather than bypass it: the same stored-energy return element, the same latch, the
same relief. And the no-auto-restart rule is what stops the E-stop from becoming a way to
resume a sweep over someone an operator hit the button to protect.

**Rejected.**
- *Freeze in place / hold position.* Recreates F3. Rejected.
- *Category 1 (controlled decel, then power removal).* The decel phase buys a smooth stop
  the machine does not need — the piston's design speed is millimetres per second
  (ADR-0007's sizing put it at ~3.7 mm/s), so there is nothing to decelerate, and the phase
  would keep the drive powered during exactly the window the E-stop was pressed to end.
- *Interior / occupant-operated E-stop.* Already rejected in ADR-0009 as a vandalism and
  abuse surface in unattended public units. Unchanged: this one is external/operator only.

**Accepted costs / to verify.** The E-stop's effectiveness now rests entirely on the same
~1.5 kN return element as SF4, so **FMEA F6** ("fail-open path does not release") covers it
too — that is the same single failure mode, not a new one, but it does mean the E-stop is no
better than that element's reliability and needs the same periodic self-test. Availability
cost: an E-stop press re-opens the cell rather than holding it closed. Rated hardware, the
safety controller, and the PL assessment remain open (as for all of SF1/SF2).

**Follow-ups.** Done: `safety_interlock.gd` gains `powered` / `estop` / `UNPOWERED` +
`_fail_open` / `_recover`; scenarios S7–S9 in `test_interlock.gd`; the TLA+ spec's SF4
claims (`Inv_EStopHalts`, `P_NoAdvanceUnpowered`, `P_NoAutoRestart`, `P_PinRelieves`) now
verify against code rather than intent. The unpowered return *rate* stays a placeholder —
it is spring force minus seal drag, and seal drag is issue #9.

---

## ADR-0024 — SF2 force cap sourced from injury/biomechanical data (100 N)
**Date:** 2026-08-04
**Status:** Accepted. Implemented in the twin, spec docs, and the pin-relief/seal-drag
sweep scripts. Hardware force-limitability check remains open (#8, gap G2).

**Context.** The FTA for roadmap #2 flagged basic event **B7**: "the 120 N cap is itself
above the injury threshold" as the fault-tree branch most worth chasing — a *systematic*
error, identical in every unit, that no redundancy defends against (`TRACEABILITY.md`
gap **G2**, issue #8). The 120 N figure in `SAFE_CONTACT_N` (`godot/physics_demo.gd`) and
the matching `F_SAFE_SUSTAINED` target in `scripts/pin_relief.py` /
`seal_drag_sweep.py` carried the comment "below the ~150 N powered-door limit" — but no
standard was ever named, and checking it (below) found the real door standard caps lower,
not higher, than that: the comparison itself was wrong, not just unsourced.

**Decision.** Set `SAFE_CONTACT_N` = **100 N**, propagated to the matching
`F_SAFE_SUSTAINED` target in the two pin-relief/seal-drag scripts. Full survey and
rationale in [`force_limit_injury_data.md`](force_limit_injury_data.md); summary:

- **FMVSS 118** (US federal power-window anti-pinch standard): **100 N**, tested down to
  a 4 mm rod representing a small child's finger — real regulatory precedent for the
  identical hazard class (a powered mechanism closing on a body part), and the only
  source surveyed validated against a sub-adult limb.
- **ISO/TS 15066** Annex A (biomechanical pain-onset limits by body region, University
  of Mainz study): **abdomen 110 N quasi-static** is the applicable worst-case region
  for H3/H8 (piston pinning a limb/torso, or the mouth-lip pinch) — hands/fingers,
  chest, neck, and pelvis are all higher (140–180 N) and not the binding constraint.
  100 N clears this with margin.
- The old "~150 N powered-door limit" comparator (ANSI/BHMA A156.19) actually caps
  normal-operation stop force at **67 N** — confirming the old 120 N cap was being
  checked against a number that was itself wrong, in the permissive direction.

**Why 100 N and not 110 N (the ISO abdomen figure).** 100 N clears *both* relevant
thresholds at once (100 ≤ 100 and 100 ≤ 110) rather than sitting between them, and it is
the one source validated against a body part smaller than an adult's — consistent with
`SAFETY.md`'s stated user model (vulnerable: intoxicated, unconscious, disabled, asleep).
It is also a real regulatory number, not a synthesized one — the property a reviewer
asking "where did this come from" needs.

**Consequences, checked, not re-derived.** `SAFE_CONTACT_N` feeds `physics_demo.gd`'s
SR-007 discrimination test (unaffected: trash-pile load ~63 N stays well under, the
non-yielding-body load ~138 N stays well over — margin preserved both directions).
`F_SAFE_SUSTAINED` feeds `pin_relief.py`'s passive-relief verdict (ADR-0009): re-run,
the qualitative conclusion is unchanged (passive relief still fails — residual pin is
1206 N either way, now ~12× the target instead of ~10×) because the return-element
sizing (`f_return`, `f_close_design` — 1567 N / 5546 N) depends on seal drag and design
margins, not on this target. This is **not** the actuator re-run tracked as issue #11 —
that item still owns re-deriving the return-element/actuator numbers once seal drag
(#9) is measured; this ADR only corrects the comparison target those numbers are
checked against.

**Rejected.**
- *Keep 120 N, drop the door comparison.* Would leave the cap unsourced again — the
  original sin gap G2 flagged. Rejected.
- *Use the ISO/TS 15066 abdomen figure (110 N) directly.* Real and sourced, but sits
  above FMVSS 118's child-finger figure; 100 N dominates both. Rejected in favour of the
  lower, doubly-anchored value.

**Accepted costs.** None functional — 100 N is a stricter cap than 120 N, so SF2 trips
earlier, not later; the only cost is a marginally higher nuisance-trip rate against
compliant/soft obstructions, judged acceptable for the safety margin bought.

**Still open.** The hardware half of issue #8: whether the real actuator + controller,
under real seal drag (#9) and real jam dynamics, can actually be held to 100 N — sim
force is a modelled quantity, not a measurement of force-limitability. `TRACEABILITY.md`
gap G2 renamed accordingly (no longer "cap unvalidated," now "drive's real
force-limitability under a jam unverified").

**Follow-ups.** Done: `godot/physics_demo.gd`, `scripts/pin_relief.py`,
`scripts/seal_drag_sweep.py`, `SAFETY.md`, `TRACEABILITY.md` (SR-007, B7, G2),
`spec/README.md`. `docs/force_limit_injury_data.md` holds the full source survey.

---
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

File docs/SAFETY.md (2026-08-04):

# HiveCell — Safety (M8, living document)

Machine-safety analysis for a powered steel piston that moves through a space people
occupy. Method: identify hazards (ISO 12100 style), rate risk, assign safety
functions. Users are assumed VULNERABLE (may be intoxicated, unconscious, disabled,
asleep) and may NOT self-rescue.

**Numbered requirements, the Hazard→Requirement→Design→Verification chain, fault trees
and the gap register are in [`TRACEABILITY.md`](TRACEABILITY.md).** This file holds the
hazards, FMEA and safety functions themselves; that one holds what discharges them —
and, more importantly, what does not.
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

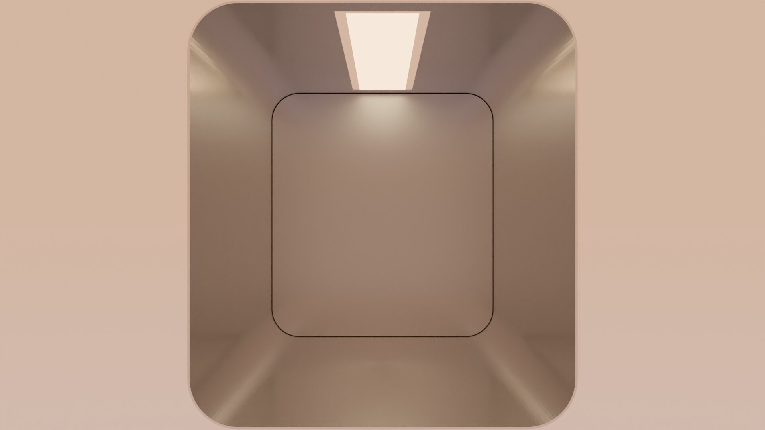
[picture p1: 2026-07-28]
assets/poster.jpg

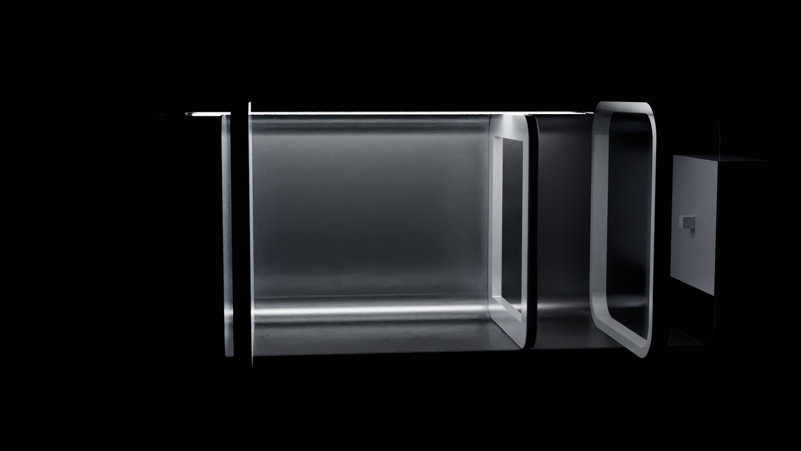
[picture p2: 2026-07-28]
assets/clean.jpg

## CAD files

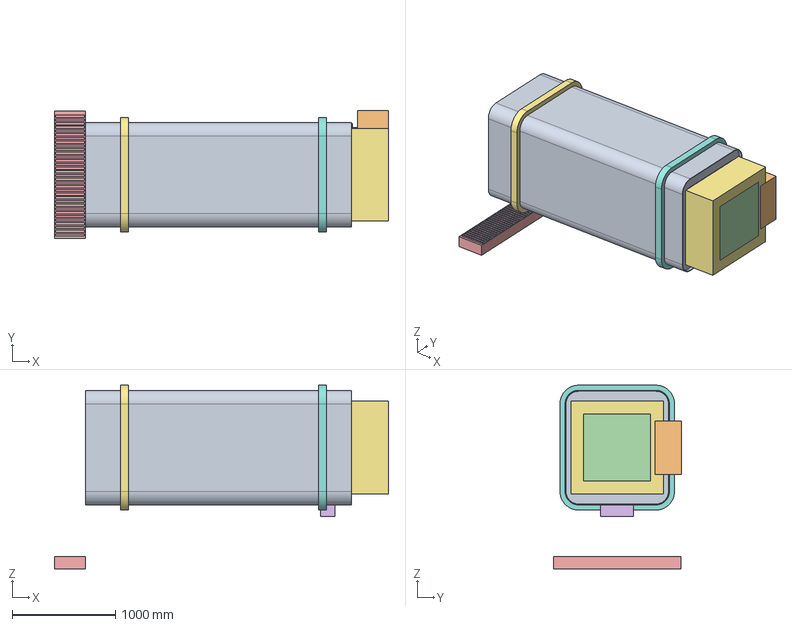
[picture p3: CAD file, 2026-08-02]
cad/HiveCell.FCStd
3240.0 x 1245.0 x 1782.0 mm
CapsuleShell
Piston
WiperSeals
ChainMagazine
ChainColumn
Luminaire
SprayRing
ServiceSprayRing
ServiceSqueegee
SqueegeeDrive
SqueegeeChain
SqueegeeYoke
TrenchDrain
SumpDrain
ServicePlant

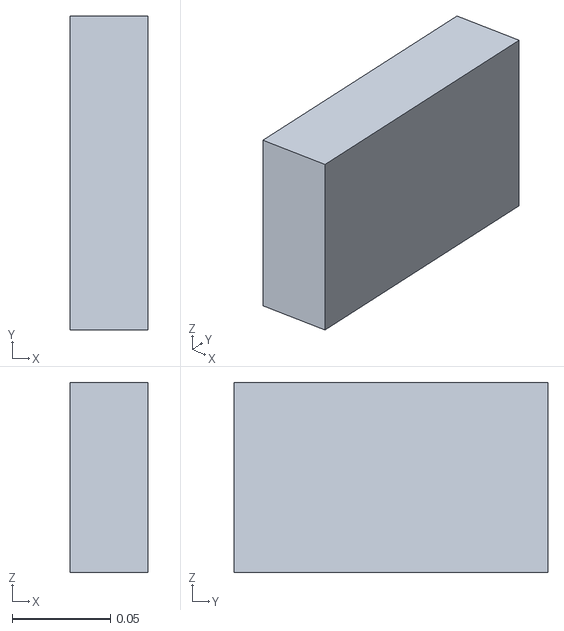
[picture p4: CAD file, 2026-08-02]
godot/models/SqueegeeYoke.obj
0.04 x 0.16 x 0.097

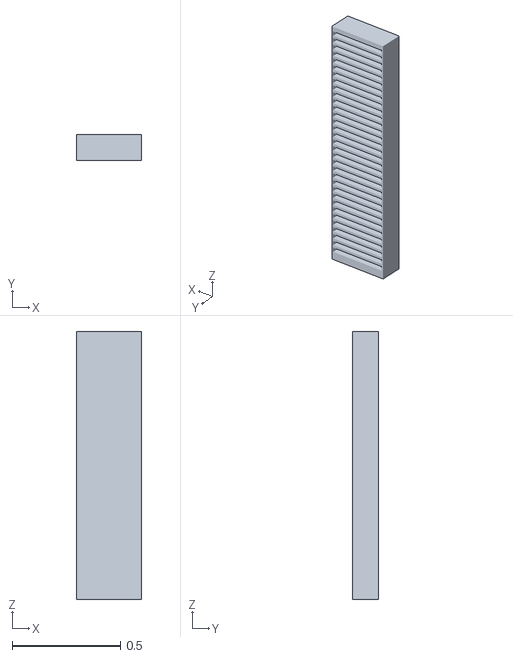
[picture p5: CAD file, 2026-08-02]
godot/models/TrenchDrain.obj
0.3 x 0.12 x 1.24

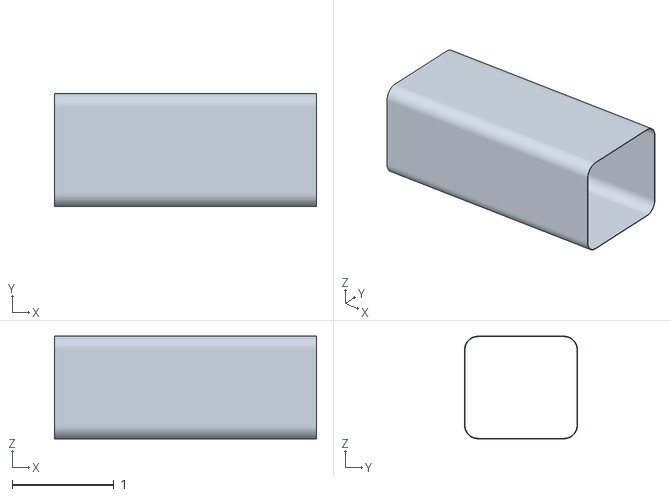
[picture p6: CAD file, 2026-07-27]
godot/models/CapsuleShell.obj
2.58 x 1.11 x 1.01

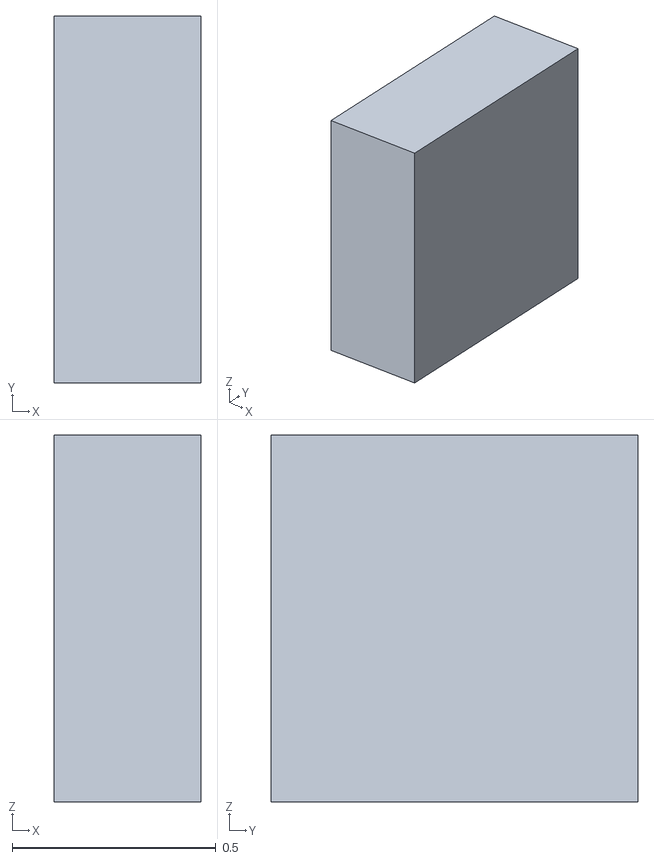
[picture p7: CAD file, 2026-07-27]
godot/models/ServicePlant.obj
0.36 x 0.9 x 0.9

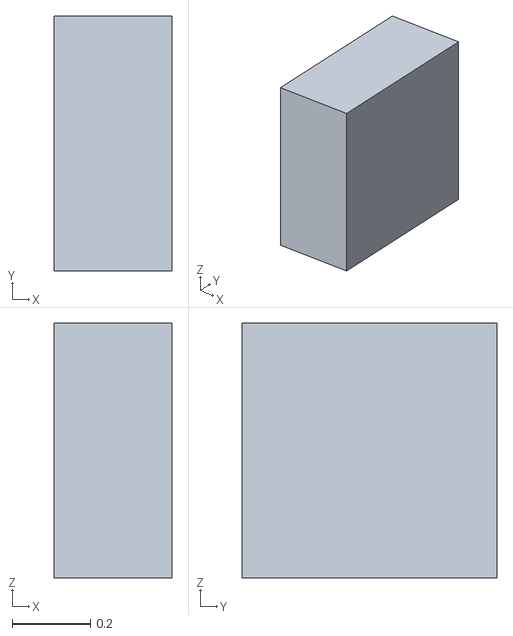
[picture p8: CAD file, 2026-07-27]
godot/models/ChainMagazine.obj
0.3 x 0.65 x 0.65

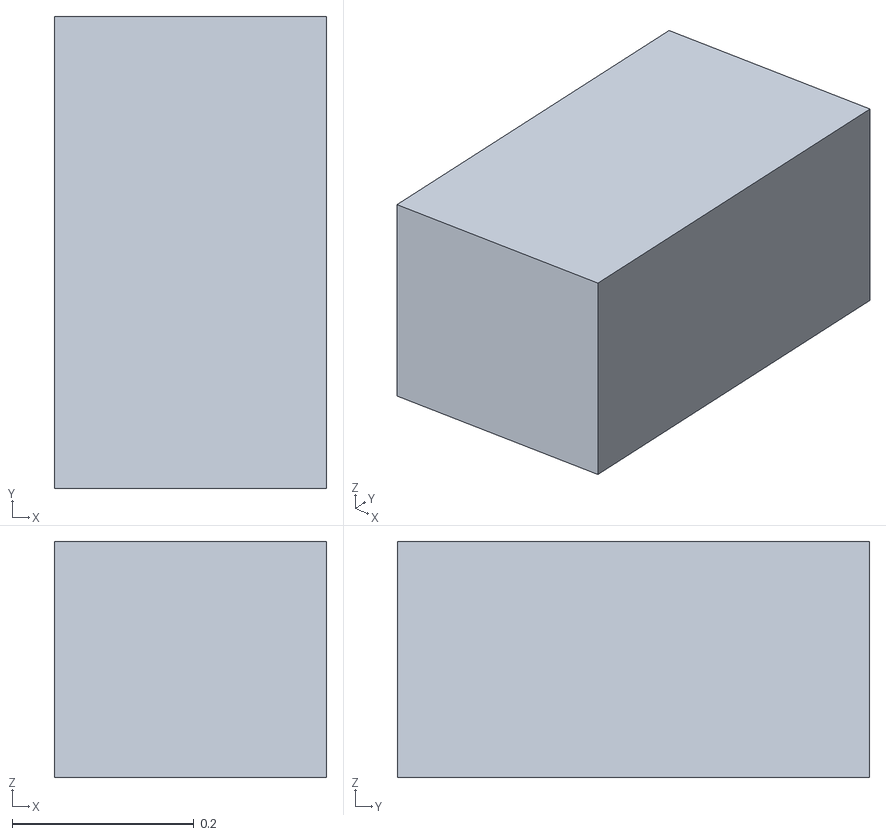
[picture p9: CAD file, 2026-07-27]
godot/models/SqueegeeDrive.obj
0.3 x 0.52 x 0.26

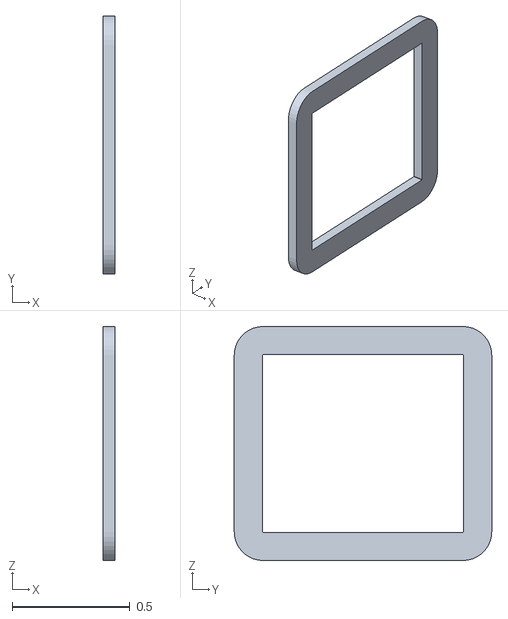
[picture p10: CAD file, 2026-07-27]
godot/models/ServiceSqueegee.obj
0.05 x 1.09 x 0.994

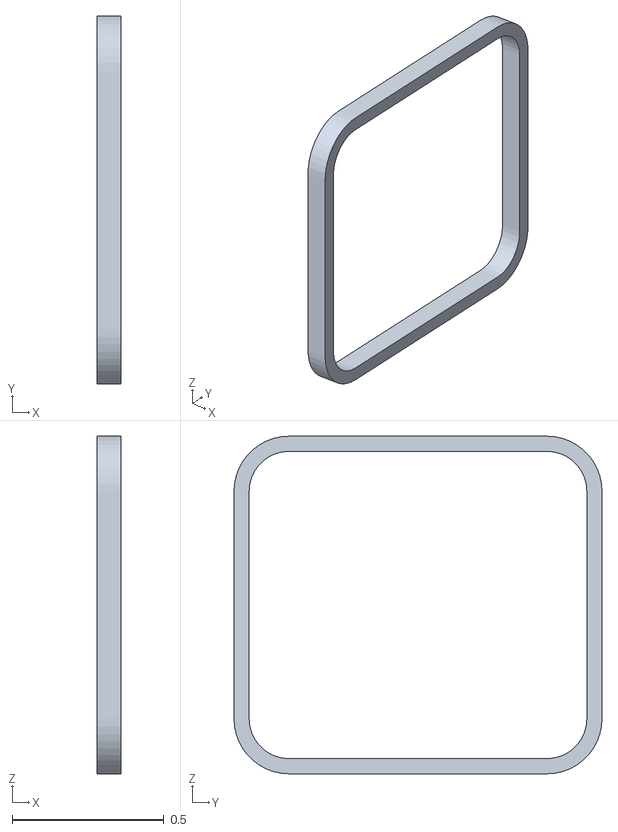
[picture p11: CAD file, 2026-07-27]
godot/models/ServiceSprayRing.obj
0.08 x 1.21 x 1.11

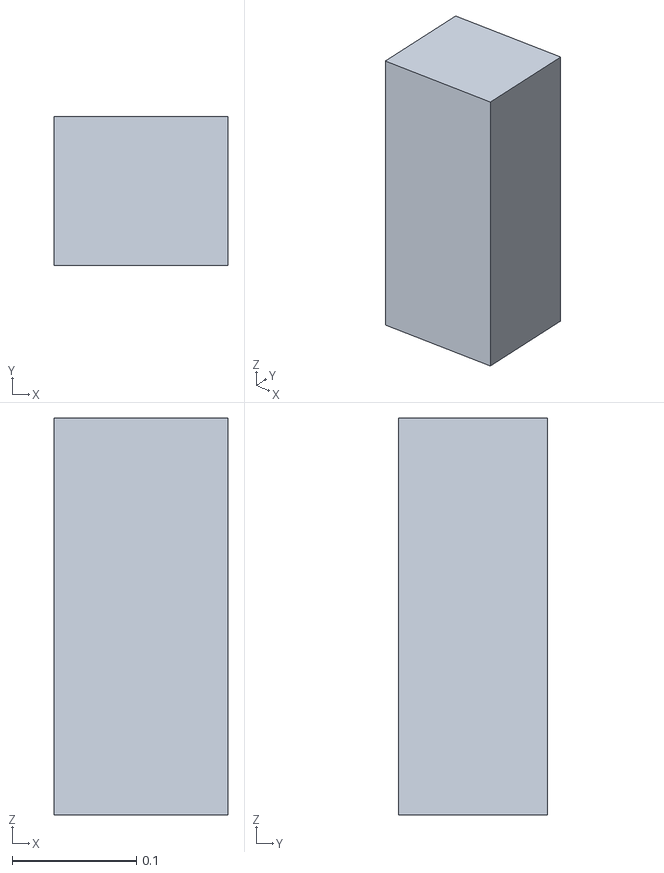
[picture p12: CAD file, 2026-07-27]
godot/models/SumpDrain.obj
0.14 x 0.12 x 0.32

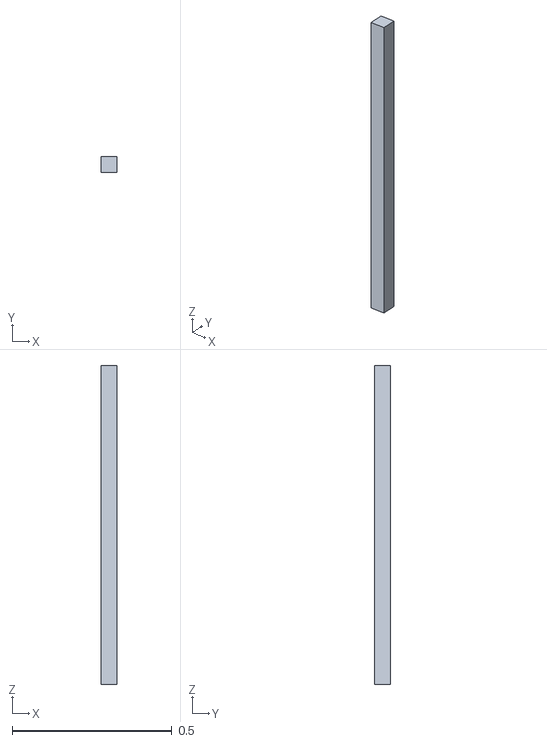
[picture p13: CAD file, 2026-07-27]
godot/models/MouthRinseBar.obj
0.05 x 0.05 x 1.00

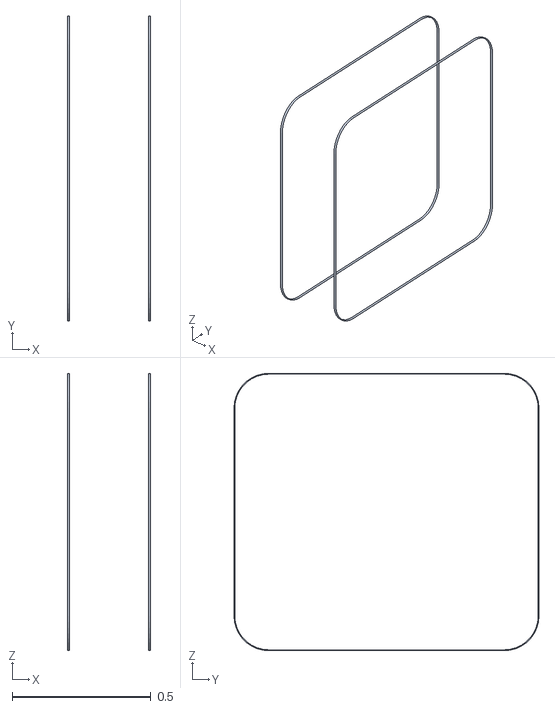
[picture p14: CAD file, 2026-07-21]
godot/models/WiperSeals.obj
0.3 x 1.10 x 1.00

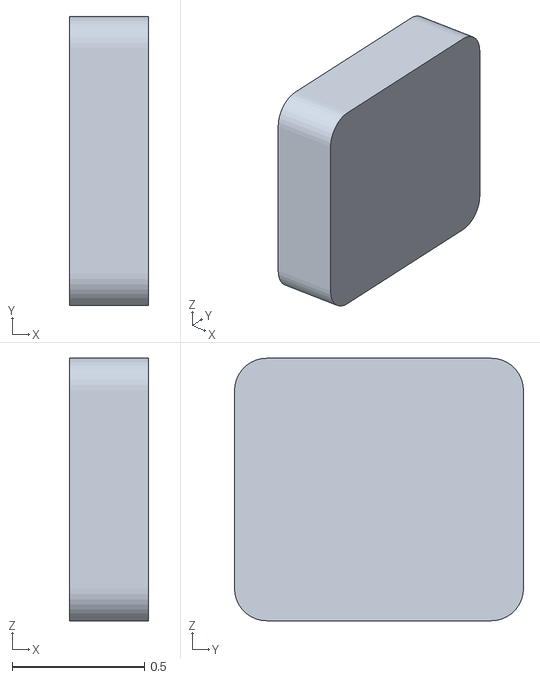
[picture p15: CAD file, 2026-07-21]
godot/models/Piston.obj
0.3 x 1.09 x 0.994

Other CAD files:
godot/models/SprayRing.obj
blender/narrative.blend

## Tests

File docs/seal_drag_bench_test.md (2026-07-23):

# Seal-drag bench test (SF3) — procedure

**Goal:** replace the single biggest estimated number in the whole design — seal
drag — with a *measured* one. Everything downstream (actuator size, the SF4 return
spring, energy per stroke, and whether ADR-0010's drive complexity is even warranted)
scales with it. Right now it is estimated across a ~40× range (**~16–700 N/m**); this
test collapses that range for a real seal sample.

> ⚠️ This is a **bench test with no occupant and no full machine**. It measures a
> friction force on a small seal coupon. It is not a test of the machine's safety
> functions. Read the safety notice in [`../LICENSE`](../LICENSE).

Related: ADR-0011 in [`DECISIONS.md`](DECISIONS.md) (why seal drag is the master
lever) and the first-principles estimate in [`../scripts/seal_drag.py`](../scripts/seal_drag.py).

---

## 1. What we are measuring, and the units that matter

The scripts model total seal force as:

```
f_seal = SEAL_DRAG_PER_M × perimeter × lips
```

where `SEAL_DRAG_PER_M` is the drag **per metre of a single lip's line contact**
(N/m), `perimeter ≈ 4.0 m` (rounded-rectangle piston cross-section), and `lips = 2`.

So the number this test must produce is **N/m, per lip**. You measure the steady
sliding force on a coupon of known contact length `L` carrying `n` lips, then:

```
SEAL_DRAG_PER_M  =  F_slide  /  (L × n)          [N/m per lip]
```

That single value drops straight into the twin (Section 6).

### The design conditions to reproduce

The real seal bridges a **3 mm running clearance per side** and scrapes a **dry,
potentially gritty** steel wall at a slow sweep speed. To be representative, the
coupon must sit at the same **interference** (lip compressed to bridge ~3 mm and
seal), run against the **same steel surface finish** you intend to use, and be tested
**dry** (the pessimistic, realistic street case) — with lubricated/PTFE runs as the
comparison that shows what a low-friction spec buys.

---

## 2. Bill of materials (~$150–250)

| Item | Purpose | Approx. cost |
|---|---|---:|
| Seal profile samples — 2–3 candidates (e.g. dry NBR/EPDM wiper lip, a PTFE-faced or silicone lip, and a brush strip) | The variable under test; get ~300–500 mm of each | $30–80 |
| Steel plate, same finish/grade as the intended bore (~150 × 600 mm) | The counter-surface the lip scrapes | $15–40 |
| Digital force gauge **or** hanging luggage/fish scale (0–20 kg / 0–200 N, ideally with peak-hold) | Reads the sliding force | $15–60 |
| Linear motion: a drawer slide, linear rail, or just a flat guided track | Keeps the pull straight and the interference constant | $10–40 |
| Clamps, a rigid carrier block to hold the coupon at a set interference, feeler gauges/shims to set the gap | Fixture | $20–40 |
| Optional: fine sand/street grit, and a small weight set to vary contact pressure | Grit case + pressure sweep | $0–20 |

A kitchen/postal scale under the plate is a valid alternative readout (measures the
horizontal drag if you build a simple pulley, or the normal load for calibration).

---

## 3. Rig — two options

**Option A — horizontal pull (simplest).** Mount the steel plate flat and fixed.
Hold the seal coupon in a carrier that presses it against the plate at the set
interference (use shims to fix the gap the lip bridges). Attach the force gauge/scale
to the carrier and pull it along the plate by hand at a slow, steady speed. Read the
**steady-state** force (not the initial break-away spike) — peak-hold helps you catch
a stable plateau.

```
   pull  <—[force gauge]—[ carrier: seal coupon pressed down ]
   ================ steel plate (fixed) ================
```

**Option B — dead-weight / inclined (self-paced).** Put the coupon on the plate
under a known normal load, tilt or use a pulley + hanging weights, and find the force
that produces steady sliding. Slower to run but needs no gauge — a scale + weights
suffice.

Either way you want: **constant interference**, **steady slow speed** (the machine
sweeps at ~3.7 mm/s — hand speed is fine; friction here is roughly speed-independent),
and the **steady sliding force**, not stiction break-away.

---

## 4. Variables to sweep

Run each candidate seal across these — they are the axes that explain the 40× range:

1. **Interference** — the compression needed to bridge ~3 mm and seal. Test the
   design value and ±1 mm around it. (This is the biggest controllable driver.)
2. **Dry vs lubricated / PTFE-faced.** Dry is the design-realistic case; the low-friction
   run quantifies what the spec change buys (ADR-0011 targets a low-friction seal).
3. **Clean vs gritty.** Sprinkle fine grit on the plate for the worst realistic case.
4. **New vs bedded-in.** Optionally run a few hundred cycles first; lips can smooth
   (drag drops) or the surface can score (drag rises).

Keep everything else fixed within a run so each row isolates one variable.

---

## 5. Procedure & data recording

1. Fix the plate; note its grade and surface finish (Ra if known).
2. Mount a coupon; set interference with shims; record the coupon's **lip count `n`**
   and **contact length `L`** (the length of plate the lip actually touches).
3. Pull steadily; record the **steady sliding force** `F_slide`. Repeat 3× per
   condition and average.
4. Compute `SEAL_DRAG_PER_M = F_slide / (L × n)`.
5. Log every run:

| run | seal | interference (mm) | dry/lub | clean/grit | F_slide (N) | L (m) | n | **N/m per lip** |
|----:|---|---:|---|---|---:|---:|--:|---:|
| 1 | | | | | | | | |

Report, per seal candidate, a **nominal** and a **worst-case** N/m. The worst-case
(dry + grit + max interference) is what the force budget must survive.

---

## 6. Feed the result into the twin / analysis

The measured N/m plugs straight into the existing scripts via the `SEAL_DRAG_PER_M`
env var (per lip). Re-run the force chain with your measured nominal *and* worst-case:

```sh
# actuator + force budget
SEAL_DRAG_PER_M=<measured> flatpak run --command=freecadcmd \
    org.freecad.FreeCAD scripts/actuator_sizing.py

# passive fail-open relief (SF4) — does the pin relieve to a safe force?
SEAL_DRAG_PER_M=<measured> flatpak run --command=freecadcmd \
    org.freecad.FreeCAD scripts/pin_relief.py
```

Run both at the nominal and the worst-case number so the design is sized for the bad
day, not the good one.

---

## 7. What the number decides (acceptance thresholds)

From the analysis in ADR-0009/0010/0011 and `pin_relief.py`:

| Measured drag | Consequence |
|---|---|
| **≤ ~13 N/m** | Passive fail-open relief alone would be safe — the SF4 return spring could shrink dramatically and ADR-0010's single-acting drive may be unnecessary. (Unlikely; a >11× reduction.) |
| **~40 N/m** (low-friction spec) | Resisting force ~333 N; passive residual pin ~333 N (~3× safe margin). Light actuator, modest spring. The target ADR-0011 is aiming for. |
| **~150 N/m** (dry elastomer nominal) | Resisting force ~1206 N; big forces; strongly motivates the ADR-0010 spring-open drive and a low-friction seal spec. |
| **> ~300 N/m** (dry + grit, stiff lip) | Forces 2–4× the model; the current mechanism assumptions need rework — reduce interference, cut to one lip, or change seal technology. |

**The decision this unblocks:** whether ADR-0010 (single-acting tension-close +
spring-open) is warranted, or a lighter drive + small spring suffices — plus freezing
the actuator and return-spring sizing. Record the measured value and the resulting
re-runs, then update ADR-0011 (and ADR-0010's status) with real data.

---

## 8. Test safety

Trivial compared to the machine, but: watch pinch points between the carrier and any
guide; secure the plate so it can't fly if you pull hard; wear eye protection if using
grit; no part of this test should ever have a person inside or near a moving piston —
there is no piston here, only a coupon.

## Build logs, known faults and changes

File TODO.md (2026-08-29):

<!-- BOARD
url: https://claude.ai/code/artifact/daa18251-ffd5-4b55-a1ee-751ffe7058e9
headline: On hold since 2026-08-05; the seal-drag bench test is the critical-path blocker gating #11, fault-injection sim is next desk work.
now:
- P0 #9 seal-drag bench test (~$200 sample, `docs/seal_drag_bench_test.md`, ADR-0011) — retires the master variable, gates #11
- P1 #3 randomized fault-injection on interlock timing (sim)
review:
-->

# HiveCell — TODO

**Status: on hold** since 2026-08-05. Narrative + priorities live in `docs/ROADMAP.md`; live discussion in GitHub Issues. This file is the actionable checklist the desktop board reads — keep the two in sync.

## Critical path (not desk work)
- [ ] #9 Seal-drag bench test (~$200 sample, `docs/seal_drag_bench_test.md`, ADR-0011) — retires the master variable, gates #11

## Next (desk work, medium)
- [ ] #3 Randomized fault-injection on interlock timing (sim)
- [ ] #4 Occupancy sensing tradeoff review — sensor table + fusion rationale (ADR-0012)
- [ ] #5 First-order reliability models — spring fatigue, cycle life, tolerance stack, ingress
- [ ] #6 Serviceability / manufacturability pass on the CAD

## Outreach (`docs/outreach.md`)
- [ ] Verify site is live and the demo video plays — https://strayeddy.github.io/HiveCell/
- [ ] First public post (Tue–Thu, 9–11am ET; stay around 3 h to answer comments)
- [ ] OSHWA certification — https://certification.oshwa.org (already qualifies: CERN-OHL-S); add UID + mark to README

## Hardware / context gated
- [ ] #7 SF1 real-sensing validation + ISO 13849 PL e dossier
- [ ] #8 SF2 drive force-limitability under a real jam (desk half done, ADR-0024)
- [ ] #11 SF4 return element + back-drive verification + actuator re-run
- [ ] #10 H4 siting sign-off vs local code + commissioning check

## Done
- [x] #1 TLA+ formal verification of interlock invariants, gated on push (found + fixed F-1, ADR-0022/0023)
- [x] #2 Safety requirements + traceability matrix + FTA (`docs/TRACEABILITY.md`)
- [x] #8 (desk half) SF2 force cap sourced from injury data, 120 N → 100 N (ADR-0024) — 2026-08-04
- [x] SF1 sensor suite: crown-mounted, CO2 dropped, load cells provisional (ADR-0025) — 2026-08-04

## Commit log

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2026-07-21 M3: capsule shell (fixed barrel) as a 6mm rounded sleeve
    - build_capsule_shell(): rounded_box_shape outer - inner boolean cut
    - open both ends (front=opening/seal, back=service); piston provides flat back
    - shelled outward (envelope stays sacred), uniform wall via concentric corners
    - barrelLength placeholder = cavityLength (extends in M4); wallThickness TBD
    - keep-out reference hidden by default
    - ADR-0004 (shell = open-ended barrel sleeve)
    [HiveCell.FCStd]
2026-07-21 M4: piston (the single moving part)
    - build_piston(): rounded plug, bore minus runningClearance (3mm/side)
    - modeled at DEPLOYED pose (front face = occupant back wall at X=cavityLength)
    - barrelLength now = cavityLength + pistonLength (2500); barrel auto-extends
    - verified 0 mm^3 overlap with shell walls (true running clearance)
    - new params: runningClearance, pistonLength
    - ADR-0005 (piston)
    [HiveCell.FCStd]
2026-07-21 M5: kinematic validation harness (swept-interference check)
    - scripts/validate_kinematics.py: steps piston through full 2200mm stroke
    - verifies no barrel collision, stays in envelope, flush at close
    - read-only; reusable interference net for future parts
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2026-07-21 Fix actuator rod mechanics: rigid translating rod, not a stretching mesh
    - rod is now fixed-length, rigid; translates with the piston and telescopes
    into a housing sized = stroke + margin (2350mm) to capture it across travel
    - honest consequence: install depth grows to 4.91m (was wrongly 3.26m)
    - twin: ActuatorRod is a real exported part translated -X with the piston
    (removed the physically-wrong CylinderMesh height animation)
    - validated headless on Godot 4.7.1-stable: imports + 180 frames, 0 errors
    - ADR-0007 updated; flags rigid-chain actuator as a compact alternative
    [ActuatorHousing.obj, ActuatorRod.obj, HiveCell.FCStd]
2026-07-21 Switch drive to rigid-chain actuator (install depth 4.91m -> 2.86m)
    - build_chain_actuator(): ChainMagazine (fixed compact coil/drive) + ChainColumn
    - rigid chain links lock straight to push, coil into a flat magazine to retract
    - twin: static magazine + procedural chain column (variable length is PHYSICAL
    here -- chain length conserved in the coil, unlike a solid rod)
    - removed stale ActuatorHousing/ActuatorRod meshes; manifest updated
    - validated headless on Godot 4.7.1: import + 180 frames, 0 errors
    - ADR-0008 (supersedes telescoping-rod depth in ADR-0007)
    [ActuatorHousing.obj, ActuatorRod.obj, ChainMagazine.obj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]
2026-07-21 M8: gate piston behind a life-detection interlock + headless self-test
    The clearing sweep now exists only to remove INANIMATE items from an
    EMPTY pod. Motion is gated behind a life-detection interlock: the
    mechanism must positively prove "no life inside" before it may advance,
    and it stops-and-reverses if life is detected mid-sweep. A living thing
    present => hold still (BLOCKED_OCCUPIED) + alert a human, never push out.
    This matches docs/SAFETY.md (H1, SF1/SF2); "push the occupant out" is
    not a mode the machine can enter.
    - safety_interlock.gd: pure, scene-free state machine + fail-safe voting
    (OR toward life; sensor fault reads occupied). Twin and test share it.
    - digital_twin.gd: delega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
2026-07-21 Add physics scenario show as the default Play scene
    A RigidBody3D/AnimatableBody3D demo driven by the SAME safety_interlock
    as the twin and its self-test. Plays on Play, looping through: empty pod,
    one item left, lots of items, someone inside (piston stays frozen), and a
    mid-sweep intrusion (stop & reverse). The piston physically pushes loose
    contents out the mouth ONLY when life-detection proves the pod empty; a
    person present => no motion. High looking-down camera to see into the pod.
    - physics_demo.gd / .tscn: the scenario show
    - project.godot: run/main_scene -> physics_demo.tscn (mechanism twin
    main.tscn/digital_twin.gd still runnable on demand)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
2026-07-21 Physics demo: use the real CAD meshes instead of primitive stand-ins
    The demo now renders and collides against the actual FreeCAD-exported
    geometry (CapsuleShell + Piston) — the same meshes the digital twin uses —
    so it is to scale and shape-accurate:
    - Shell: StaticBody3D with concave (trimesh) collision from CapsuleShell.obj,
    drawn semi-transparent so the interior reads from the top-down camera.
    - Piston: AnimatableBody3D with convex-hull collision from Piston.obj,
    retracting -X by `stroke` (from the manifest) exactly like the twin.
    - Bore dimensions (floor, width, mouth, cavity extent) derived from the
    shell mesh AABB, so this stays in sync if the CAD is re-exported.
    - Items sc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
2026-07-21 Model SF2 contact-force reaction (safety edge) as an independent trip
    The discriminator is YIELD, not resistance magnitude: movable trash slides
    away so its force stays low and bounded; a non-yielding body (a braced limb)
    makes force climb steeply with penetration -- the crush SF2 must catch.
    - safety_interlock.gd: add `contact_over_limit` (SF2), an independent trip
    alongside SF1 life-detection. Either reverses a sweep; LIFE_CHECK also
    refuses to start while the safety edge is tripped (a stuck edge = no motion).
    - test_interlock.gd: invariant generalized to both trips; new scenario proves
    SF2 reverses the sweep even when SF1 is blind (occupant_alive stays false).
    - physics_demo.gd: dr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
2026-07-21 M9 SF3: wiper seal — fills the 3mm shear gap (hazard H2)
    Adds the compliant wiper/brush seal that was deferred ("seals bridge the
    gap, added later") so there is no open moving 3mm shear line.
    CAD (source of truth):
    - build_model.py: new params (sealLipThickness/LipCount/Interference) and
    build_wiper_seals() — two lip rings on the piston perimeter filling the
    runningClearance gap. Verified: touches the bore and hugs the piston with
    ~0 overlap; 2 lips x 8mm, 190.8 cm^3.
    - actuator_sizing.py: seal drag now counts both lips — 2 x ~4m @ 150 N/m =
    ~1190 N, the dominant load; design force ~2411 N. Drag remains the biggest
    unknown (150 N/m assumption).
    Twin:
    - export_godot.py: expo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
    [HiveCell.FCStd, WiperSeals.obj]
2026-07-21 SAFETY.md: FMEA for the trap/crush chain + reframe SF4 to a fail-open drive
    Add a component-level FMEA for the drive/interlock failure chain. The driver
    is F3: SF1 misses an occupant AND power is lost mid-contact -> a self-locking
    drive holds a sustained pin with no powered reverse. Severity 4 with nothing
    able to act once power is gone, so it must be designed out (ALARP), not just
    made unlikely.
    Decision: reject an occupant-operated manual release + interior E-stop (F7) --
    in unattended public units it's a vandalism/abuse surface, and geometry already
    removes the sealed-in trap (occupant is always mouth-side of the piston, F4/F5).
    Replace with an inherent requirement: the drive must not su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
2026-07-21 ADR-0009: SF4 fail-open drive + passive flush latch; "stay closed w/o power"
    Records the SF4 decision from the FMEA and adds the new requirement that a
    fully-closed pod stays closed without power. Key insight: the fail behavior is
    POSITION-DEPENDENT, which reconciles the two:
    - occupant zone -> back-drivable, so a power-loss pin (F3) relieves passively;
    - flush end -> a PASSIVE latch holds it closed with zero power, engaging only
    where no occupant can be (security + vandal resistance + no standby energy).
    No occupant-operated release/E-stop (vandalism surface; geometry already removes
    the sealed-in trap). Notes that a motor-side declutch can't work (chain self-lock
    is intrinsic/downstream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
2026-07-21 SF4 pin-relief check: passive relief insufficient -> return element required
    Add scripts/pin_relief.py (first-order): on power loss a back-drivable piston
    stalls when the tissue reaction equals the seal drag, so without help the
    residual pin floors at the resisting force ~1.2 kN -- about 10x a safe sustained
    contact force (120 N). Passive relief alone FAILS.
    Consequences recorded in ADR-0009 and SAFETY.md:
    - A ~1.5 kN stored-energy return element (spring/gas strut, held off by the flush
    latch at close) is required to actually unload a pinned occupant.
    - Cost: closing design force ~2.3x (2411 -> ~5546 N) -> re-run actuator sizing.
    - Reducing seal drag enough (<=~13 N/m, >11x cut) isn't cre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
2026-07-21 ADR-0010 (proposed): single-acting tension-close + spring-open drive
    Revisits the actuator choice now that ADR-0009 (SF4) wants a back-drivable drive
    and pin_relief.py mandates a ~1.5 kN return spring. Those changes negate two of
    rigid-chain's three original advantages (self-locking hold is now a liability;
    holding moved to the flush latch), leaving only shallow depth -- which other
    options match.
    Proposed: a tension member (toothed chain/belt or cable) pulls the piston closed;
    the mandatory SF4 spring pushes it open. Fail-open by nature (a cable can't push),
    reuses the safety spring as the deploy actuator, stays shallow, simpler/cheaper
    than rigid-chain. Costs flagged: damped deploy (~3.4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
2026-07-21 README: add a Safety status section
    Summarize the safety functions (SF1/SF2 sim + self-test, SF3 CAD, SF4 decided,
    SF5 todo), the PREVENT->REACT->fail-safe principle, and the biggest open risk
    (seal drag as the master variable, must be measured). Points at SAFETY.md and
    DECISIONS.md for detail; states plainly this is design/sim, not certified hardware.
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2026-07-22 ADR-0012: SF1 occupancy-sensing architecture (diverse-redundant, PL e)
    SF1 is the primary safeguard but had only simulated voting logic -- no physical
    sensor suite, redundancy architecture, or performance level. ADR-0012 fixes that:
    - Target ISO 13849-1 PL e, Cat 3-4 (risk graph S2+F2+P2) on a rated safety
    controller -- justified by a may-not-self-rescue occupant.
    - Diverse-redundant suite so no common-cause failure blinds it: mmWave/UWB
    vital-sign radar (primary; still/cold/blanketed occupant), thermal IR array,
    NDIR CO2, floor load cells + ballistocardiography; optional mouth light-curtain.
    - Fail-safe voting matching the sim: OR toward life, AND toward clear, fault =
    occupied, div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
2026-07-22 SAFETY.md: add H4 siting rules (facility-level fall-from-mouth)
    Close the last untreated hazard row. H4 (fall from an elevated mouth) is
    mitigated by INSTALL constraints, not a device function: prefer the mouth at
    floor level; elevated mouths must open onto a guarded same-level landing/gallery;
    clear non-slip approach; stacked "wall of cells" gets an access gallery. Second
    layer behind the SF1 interlock; enforced by a commissioning acceptance check, not
    at runtime. Thresholds flagged as placeholders pending the governing building code.
    Addressed line + open item updated.
2026-07-22 H4 siting: sitting-height mouth (accepted single-layer risk trade)
    Per design decision, the mouth sill is set at ~sitting height (~450-500mm) so
    ejected items fall clear of the opening instead of piling, and for sit-and-swing
    entry. This removes the floor-level fall protection, so H4 fall protection now
    rests solely on SF1 -- a conscious departure from "never the sole defense,"
    accepted because SF1 is diverse-redundant PL e (+ SF2 backstop) and the residual
    fall is low (~500mm, ~a high step). Documented transparently as accepted, not
    overlooked: still require a forgiving non-slip drop-zone, no stacking a mouth over
    a real drop, and a named risk-acceptance sign-off at commissioning.
    H4 hazar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
2026-07-22 Add fem_piston.py: FreeCAD-FEM structural check of the piston
    Native-toolchain FEA (FreeCAD FEM -> CalculiX ccx + gmsh, all bundled in the
    Flatpak; no Wine). Meshes the piston, assigns stainless 304, applies gravity +
    a design face load, solves, reports max von Mises, max displacement, and mass.
    Validated headless:
    - SOLID (default): mass 2579 kg, ~0 stress (SF ~5700) -- quantitatively confirms
    the piston MUST be lightweighted (matches actuator_sizing).
    - SHELL (WALL_MM=6): open-backed 6mm shell mass ~107 kg (useful cross-check vs the
    ~160 kg area estimate).
    Honesty guard: a coarse tet mesh on a thin wall (<2 elements through thickness)
    under-resolves bending, so the script now WARNS a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
2026-07-22 fem_piston.py: apply all 3 loads (self-weight + actuator thrust + occupant)
    The first cut only applied self-weight + one face load. Rewrite the load
    model to the task spec: gravity + the 5546 N closing-stroke actuator thrust
    (from actuator_sizing.py) on the rear cap + a representative occupant load on
    the front cap, reacted by a fixed perimeter guide band so the two large flat
    caps carry the loads in bending.
    Findings: the 6 mm shell (open service side) is ~107 kg, confirming the 160 kg
    estimate in actuator_sizing.py is a conservative upper bound; stress is far
    from binding (SF > 12 even at 10-50x the coarse peak) -- mass drives the design.
    Document the RAM limit: a reliable thin-wall SOLID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
2026-07-22 twin: move siting into physics_demo (the real main scene); drop main.tscn
    physics_demo.tscn is the project's run/main_scene, and it is strictly more
    capable than main.tscn (real collision, physics-swept items, 6 scenarios), so
    the siting work belonged there, not in the redundant digital_twin scene.
    - delete main.tscn / digital_twin.gd (redundant); port its rigid-chain column
    into physics_demo so nothing is lost;
    - ground plane `sill_height` (0.5 m) below the bore floor, so ejected items
    physically fall that ~500 mm CLEAR onto a forgiving surface (ADR-0013 intent);
    - the cell is set INTO a wall: a 4-bar picture-frame facade (StaticBody bars) at
    the mouth plane, sill ~500 mm above groun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
2026-07-23 render: add scenario cinematic (piston sweep / occupant-safe beats)
    blender/scenario_cinematic.py renders one BEAT of a scenario cinematic that
    mirrors the Godot twin (physics_demo.gd): the piston sweeps loose items out the
    mouth, but a living occupant is never pushed — motion locks, or stops and
    reverses. Three beats: "clear" (sweep items out), "locked" (person inside -> no
    motion), "intrude" (someone reaches in mid-sweep -> stop & reverse).
    The camera looks through the mouth opening so the solid steel interior reads
    without transparency; a distinct palette (gold piston / steel bore / concrete
    wall / RGB items) keeps the parts apart. Swept items are a baked rigid-body sim
    (the animated p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
2026-07-23 ADR-0014: interior lighting (warm, occupancy-staged, top status) across CAD/twin/render
    Interior light has three conflicting jobs — orient on entry, show status, and not
    prevent sleep — for vulnerable, non-self-rescuing users in a sealed steel cavity.
    ADR-0014 resolves it with one warm, blue-depleted (<=2200K) flush luminaire in the
    barrel CROWN: occupancy-staged off SF1 (brief ~20-50 lx entry -> ~1-5 lx night-glow),
    top-mounted so a body/bedding can't cover it and the top wiper cleans it each sweep.
    It IS the interior status indicator, but the saturated colours (green available / red
    in-movement) show only while the pod is EMPTY; the instant it is occupied it holds warm
    amber, so status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
    [HiveCell.FCStd]
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2026-07-23 SF1: model the diverse-redundant fusion, wire it into interlock + twin
    Replace the stub OR in safety_interlock.gd with a real fail-safe occupancy
    voter (ADR-0012):
    - godot/occupancy_fusion.gd: four diverse channels (radar vitals / thermal /
    NDIR CO2 / load-BCG), each reducing raw inputs to CLEAR/OCCUPIED/FAULT with
    four fault modes (unhealthy / out-of-range / stale). occupied() encodes the
    three rules -- OR-toward-life, fault=occupied, AND-toward-clear (empty only
    when every channel positively reads clear) -- plus a runtime self_test().
    - safety_interlock.gd: life_present() consults the fusion when attached and
    step() ages the channels. Backward-compatible: the interlock tests att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
2026-07-25 cinematic: rework "One Night" into two shots; bake a hand-editable blend
    Replace the 9-cut hero-following edit with two cameras where the wall is
    the protagonist: S1 a wide drifting frame of the living wall (walkers,
    sleepers, a sitter, a resident leaving while their cell sweeps closed and
    a neighbour reopens), S2 a close lateral dolly along the cell faces that
    eases to a stop as the guest wakes, leaves, and the piston sweeps the
    cell clean. One hard cut, keyed on adjacent frames.
    Every neighbour is now a FULL clone of the hero cell (shell, piston,
    wiper seals, chain magazine/column, luminaire) -- linked mesh data except
    the luminaires, which get unique data for per-cell state colours in
    Ph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
    [narrative.blend]
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2026-07-27 cad: ADR-0015 cleaning subsystem space-claim + export sync
    Design the deferred cell-cleaning subsystem (component-tree #6) as a
    motion-driven "wash-in-transit" with thermal + chemical sanitize, plumbed
    to city mains/sewer. The piston sweeps its face + bore past a flush wash
    manifold (detergent -> 82-90 C hot water/steam -> disinfectant); a mouth
    rinse bar + sloped tray purge the sill and exterior face-edge on a
    crack-open/close/dry choreography, draining to sewer. Rejects pyrolytic
    burn (destroys seals/luminaire/sensors, warps the running fit). Full
    rationale + rejected alternatives in ADR-0015.
    - build_model.py: WashManifold, MouthRinseBar, DropTray, FloorDrain,
    ServicePlant as represent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
    [DropTray.obj, FloorDrain.obj, HiveCell.FCStd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]
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2026-07-27 cad: ADR-0016 — keep cleaning off the public face (vandal resistance)
    The exterior MouthRinseBar + hanging DropTray broke priority #1 (they sit on
    the street face, exposed even when closed). Capturing debris internally was
    rejected: it breaks the core invariant (push everything OUT the mouth, trap
    nothing, service side sealed). So: drop MouthRinseBar/DropTray/FloorDrain, slope
    the bore to the mouth, and add a flush grated pavement TrenchDrain -> sewer,
    serviced from below. Closed = only the flush piston face + a bolted grate.
    ADR-0016 in DECISIONS.md; CAD parts + exports + anatomy diagram updated.
    [DropTray.obj, FloorDrain.obj, HiveCell.FCStd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]
2026-07-27 cad: ADR-0017 — wash media drains to an internal piston-hidden sump
    ADR-0016 over-corrected by sending everything (incl. hot chemical wash water)
    out the mouth. Split the drainage: gross solids ride the sweep out the mouth to
    the pavement grate (TrenchDrain); the wash media (hot water + chemicals) drains
    to an internal back sump (SumpDrain) -> sewer. The sump sits UNDER the piston
    when it is deployed to the very back, so it's covered when the cell is open and
    behind the flush face when closed -- never a grate in the occupied cavity or on
    the public face (more vandal-resistant than a street drain, not less).
    [HiveCell.FCStd, SumpDrain.obj]
2026-07-27 cad: ADR-0018 — two spray rings (front past the piston + hidden deep ring)
    A single mouth-side ring sits inside the closed piston's ~300 mm body, so it
    can't reach the sealed chamber. Split into two: SprayRing (front) moves to just
    past the closed piston (X=pistonLength+40) to spray the chamber's front + rinse
    the face in transit; a new ServiceSprayRing sits behind the deployed piston face
    (never in the occupant space) to wash the chamber's far end when closed. Together
    they cover the whole sealed chamber. Resolves the ADR-0017 nozzle-placement TODO.
    [HiveCell.FCStd, ServiceSprayRing.obj]
2026-07-27 cad: ADR-0019 — spray-and-squeegee method + a traveling service squeegee
    Picks Option 1 (fixed rings wet/dose; wipers scrub + drive-to-drain) and adds a
    ServiceSqueegee: a wiper that runs the full sealed chamber while the piston is
    parked flush -- a car wash over the stopped piston, scrubbing from inside and
    pushing the wash media to the sump. Lives entirely service-side/hidden. Stowed
    via option (b): the barrel is extended 80mm (squeegeeStow) to house it behind the
    deployed piston; install depth 2.86 -> 2.94 m. Also fixes the sump X formula to be
    robust to barrel length. It's a new mover (added to moving_parts); drive + wash
    hydraulics are TBD (bench gates recorded in ADR-0019).
    Co-Autho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
    [HiveCell.FCStd, ServiceSqueegee.obj]
2026-07-27 cad: ADR-0020 — squeegee drive = a dedicated, swappable rigid-chain unit
    The ServiceSqueegee gets its own compact rigid-chain drive (SqueegeeDrive)
    rather than a shared clutch, a water-pig, or a screw. Chosen for serviceability:
    an independent module that nests beside the piston's actuator (no added depth)
    and can be bench-tested + swapped on its own. Space-claim added; the offset->
    central coupling (a yoke, no wall slot) and motor sizing are TBD.
    [HiveCell.FCStd, SqueegeeDrive.obj]
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2026-07-31 narrative: reference hivecell for service parts + fix pedestrian foot-slide
    narrative.blend now links SprayRing/ServiceSprayRing/ServiceSqueegee mesh
    data from hivecell.blend (object-level material override) instead of holding
    editable local OBJ copies -- matching the 54 core cell parts. TrenchDrain (the
    grate) stays local by design. narrative_link_clean.py's import_obj() is
    replaced by link_part() so re-runs link from hivecell, not re-import.
    Also retime the six background walkers: their empties travelled 2x-12x faster
    than the in-place walk cycle's stride (Walker2 12.6 m/s, Walker3 popped 20 m in
    one frame) on eased curves. Measured the clips' stride (~1.0 m/s) and set a
    constant LINEAR ~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
    [narrative.blend]
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2026-08-02 cad: ADR-0021 squeegee-drive coupling — in-bore offset chain + yoke
    Resolve ADR-0020's parked coupling question: how the OFFSET SqueegeeDrive
    pushes the CENTERED squeegee ring with no wall slot (ADR-0007).
    Run the drive's rigid chain INSIDE the sealed bore in an offset +Y lane
    (squeegeeChainOffsetY=430, wall at 500) + a short rigid SqueegeeYoke to the
    ring's +Y frame; the bore guides against rack. Sound by temporal exclusivity:
    piston (central) and squeegee (offset) never share the chamber at once — open
    => squeegee stowed behind the deployed piston, cleaning => piston flush at the
    mouth so the whole chamber is free. CAD confirms 0 cavity intrusion + install
    depth unchanged (2.94 m). Fi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
    [HiveCell.FCStd, SqueegeeYoke.obj, TrenchDrain.obj]
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2026-08-03 safety: formally verify the interlock (roadmap #1) + ADR-0022/0023
    The interlock's safety claims were only ever checked against hand-written
    scenarios. This adds a TLA+ model (spec/HiveCellInterlock.tla) that machine-checks
    them over every reachable state, and wires TLC into scripts/run_selftest.sh so the
    existing pre-push hook gates it. No JRE => skipped with a warning rather than
    blocking; tla2tools.jar is fetched to ~/.cache/hivecell, nothing vendored.
    Three runs: an adversarial environment (any sensor reading, any trip, any
    power/E-stop event, people entering and leaving, every tick) for the safety
    claims; a benign one for liveness, so a frozen machine can't pass; and one that
    is FMEA F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
    [Blackout.cfg, Liveness.cfg, Safety.cfg]
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
